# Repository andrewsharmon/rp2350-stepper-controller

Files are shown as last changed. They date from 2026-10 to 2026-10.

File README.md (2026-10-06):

# RP2350 coordinated stepper controller

> **Work in progress.** Firmware runs on a Raspberry Pi Pico 2 bench setup.
> The custom board designs are an **unreviewed feasibility first pass**:
> schematics only, no PCB layout, not checked against datasheets or built.
> Don't fabricate them as-is.

A very low-cost, compact controller for up to **10 small stepper motors** (8 mm
micro steppers, 28BYJ-48 converted to bipolar, about 0.2 A per coil or less).
It's aimed at kinetic art first, then lab and robotics use.

There are no stepper-driver ICs. The RP2350 generates sine-PWM microstepping
itself (voltage mode), using PIO state machines fed by DMA, into cheap
DRV8833-class dual H-bridges (AT8833).

## Status

| # | Milestone | State |
|---|---|---|
| 1 | Hardware spec and KiCad schematics for all three boards | first pass, **not reviewed** (open part picks in [hardware/README.md](hardware/README.md)) |
| 2 | One motor: sine PWM via PIO + DMA | done, verified on hardware |
| 3 | 10-axis PWM, ADC monitor, e-stop/button ladder, WS2812 | done on Pico 2; ladder buttons not yet bench-wired |
| 4 | Trajectory generators and profiles, jog modes, telemetry | done (text telemetry; binary framing comes with milestone 5) |
| 5 | Coordinated groups and planner, USB protocol, host tool | done |
| 6 | I²C target, cam/LED shows, flash config, standalone mode | done; I²C target written for the RP2354B board but **untested** (no free pins or I²C master on the bench) |
| 7 | PCB layout, fab, bring-up of the board stack | |

What works today (measured on a Pico 2 + DRV8833 + 8 mm stepper):

- **PWM:** 20 kHz, four-segment H-bridge PWM with slow-decay brake off-time and 1/256-step sine microstepping. Duties below the driver's 0.5 µs minimum pulse are error-diffused.
- **10 axes:** each has its own position, velocity or jog mode on a 1 kHz trajectory tick. Drive amplitude depends on speed, with lower holding current at standstill. Core 1 is about 33-35% loaded, core 0 about 0.5%.
- **Coordinated groups:** up to 4 groups, each owning a set of axes. A group follows a queue of straight lines and arcs in joint space, with every axis starting and finishing together. Lookahead keeps it moving through gentle corners and chord-split arcs, and no axis exceeds its own limits. On the Pico 2, a 300-step-radius circle ran at a constant 800 steps/s and closed exactly.
- **Shows:** keyframe tracks for axes and LED pixels on one timeline, written as JSON, compiled and uploaded to one of 4 flash slots. Axes pass exactly through every keyframe (played as PVT), LED colours fade between keys, and shows can loop. A show is refused if any segment would exceed an axis's speed or acceleration limit. On the Pico 2, a looping 10-axis wave with 9 LED tracks hit all 360 keyframes checked exactly over 2.5 loops.
- **Standalone mode:** a boot show (saved in the configuration) starts at power-up with no computer attached. Btn1 clears a latched stop once the e-stop is closed again, or starts / stops the selected show; Btn2 selects the next stored show, switching to it if one is playing.
- **Configuration in flash:** per-axis limits, motion profile, automatic amplitude curve (run low/high, hold, corner speeds) and wiring fixes (reverse direction, swap coils) survive power cycles. Two sectors are written alternately with a generation counter and CRC, so an interrupted save keeps the previous configuration.
- **Streamed PVT:** the host sends position/velocity/time points, and each axis follows a cubic through them. A 10-axis wave streamed at 20 ms per point tracked the ideal curve within 0.0005 steps. Running out of points while moving brakes safely.
- **Telemetry:** up to 1 kHz with selectable axes and fields (position, speed, mode, amplitude, PVT queue, plus motor voltage, ladder, stop state and the last applied command). Each line is numbered so a host can detect drops. Event lines report finished moves, PVT underruns and stops. At 1 kHz with every field on 10 axes, no lines were dropped and core 0 was 39% busy.
- **Electronic cams:** an axis can follow a cam table, so its position is a function of a leader's position: another axis, or one of two virtual leaders with their own speed ramps. Because it's position-based, followers retrace exactly when the leader reverses, at any speed. Cyclic tables can carry a net rise per cycle. Engaging blends in smoothly, and is refused if the follower couldn't keep up at the leader's limits. On the Pico 2, followers matched an independent evaluation of the cam within 0.0013 steps through forward and reverse runs. `save` also stores the loaded cam tables in flash; they are restored at boot.
- **Motion profiles per axis:** `trap`, `scurve` (the default: jerk-limited by a moving average, Tj = 30 ms), `smooth` (two moving averages), `cosine` and `quintic`. Every profile lands exactly on its target within the speed and acceleration limits, and moves can be redirected mid-move without jumps.
- **Safety:** an e-stop or driver fault on the analog ladder cuts all outputs in about 30 µs. A watchdog on core 0 drops outputs to coast if core 1 stalls.
- **Status LEDs:** a WS2812 chain shows overall status plus each axis's speed and direction.

How it works, from trajectory planning to PIO pin toggling: [docs/THEORY.md](docs/THEORY.md).

## Repository layout

```
tools/stepperctl/    host library + command line (binary protocol)
tools/shows/         example shows (JSON; format in tools/stepperctl/show.py)
tools/cams/          example cam tables (JSON: {"cyclic": true, "points": [[x, y], ...]})
tools/pvt_demo.py    host demo: streams a PVT wave over USB serial
firmware/            Pico SDK (C) firmware
  src/               motor PWM (PIO/DMA), microstepping, ADC monitor, ladder, LEDs
  boards/            board header for the custom RP2354B controller
  test/test_host.c   host-side tests (PWM encoder, microstep math, ladder, motion)
  tools/             sine table generator
hardware/            spec, KiCad schematics and BOMs (generated by hardware/gen)
```

## Building the firmware

Requirements:
- [Pico SDK](https://github.com/raspberrypi/pico-sdk) 2.1.1 (set `PICO_SDK_PATH`);
- an `arm-none-eabi` GCC toolchain;
- CMake and Ninja.

```bash
# Custom RP2354B controller (default board)
cmake -S firmware -B firmware/build -G Ninja
cmake --build firmware/build

# Raspberry Pi Pico 2 bench setup
cmake -S firmware -B firmware/build-pico2 -G Ninja -DPICO_BOARD=pico2
cmake --build firmware/build-pico2
```

Options: `-DNUM_MOTORS=1..10` (default 10), `-DLADDER_BYPASS=ON` (bench without
a ladder wired; never use with motors you can't stop by hand), `-DBOOT_TRACE=ON`.

Flash by copying `stepper.uf2` to the board in BOOTSEL mode, or with picotool:

```bash
picotool load -x firmware/build-pico2/stepper.uf2
```

Host tests (no hardware needed):

```bash
cd firmware/test
cc -std=c11 -O1 -Wall -Wextra -DCONFIG_HOST_TEST -I../src test_host.c ../src/hbridge_encode.c \
   ../src/microstep.c ../src/sine_lut.c ../src/ladder.c ../src/motion.c ../src/group.c \
   ../src/frame.c ../src/config.c ../src/show.c ../src/standalone.c ../src/cam.c ../src/cam_store.c \
   -lm -o test_host && ./test_host
```

## Pico 2 bench setup

| Pico 2 | Connects to |
|---|---|
| GP0-GP3 | motor 1: DRV8833 module AIN1, AIN2, BIN1, BIN2 (motors 2-5 on GP4-GP19) |
| GP20 | WS2812 chain data in (pixel 0 status, pixels 1-10 axes) |
| GP26 | ladder: 10k to 3V3, 20k to GND (idle); see [hardware/README.md](hardware/README.md) |
| GP28 | board ID (optional) |
| VBUS / GND | DRV8833 VM and GND; pull the module's sleep pin (EEP) high |

Motors 6-10 have no pins on the Pico 2, but their state machines and DMA still
run, so the full 10-axis load is exercised.

The USB serial console takes line commands (type `help`). Some examples:

```
m 1 500          move axis 1 to 500 full steps
mr * -100        move every axis back 100 steps
j 3 400          jog axis 3 at 400 steps/s (stops unless repeated within 300 ms)
lim 1 1200 4000  axis 1 limits: 1200 steps/s, 4000 steps/s^2
prof * quintic   minimum-jerk moves on every axis (axes must be at rest)
cam 1 cyclic 0,0 100,40 200,50   cam table 1 (leader x, follower y); +50 per 200-step cycle
vl 1 lim 150 150 virtual leader 1 limits; ce 3 1 v1 makes axis 3 follow cam 1 behind it
vl 1 vel 100     run the virtual leader (negative reverses; followers retrace)
g 1 1,2 800      group 1 = axes 1 and 2, path speed 800 steps/s
gl 1 400 400     group line to (400, 400); ga 1 -300 0 360: full circle around (-300, 0)
p 2 150 300 20   PVT point: axis 2 reaches 150 steps at 300 steps/s, 20 ms after the last
pgo 1,2          start axes 1 and 2 following their queued points on the same tick
t 100            100 telemetry lines/s (header line names the columns)
tf pos,vel,mode  per-axis telemetry fields; ta 1,2 picks axes, ts adds system fields
te on            event lines: E <tick> done <ax> <pos>, underrun, stop, clear
echo off         for scripts: no echo or prompt
drive 1 40 60 25 axis 1 amplitude: 40% at low speed, 60% at high speed, 25% holding
dir 2 rev        reverse axis 2 (coils 2 ba swaps its coils)
cfg / save       show the configuration / write it to flash (axes at rest)
?                status, loads and per-axis table
```

### Host tool (binary protocol)

The same USB port also speaks a framed binary protocol (COBS + CRC-16; the
message spec is [firmware/src/protocol.h](firmware/src/protocol.h)). Frames
and the text console coexist: binary frames are wrapped in 0x00 bytes, which
the console never sends. `tools/stepperctl` is a standard-library Python
client and command line:

```bash
python3 tools/stepperctl ping
python3 tools/stepperctl move 1,2 250 --wait
python3 tools/stepperctl group 1 create 1,2 --feed 800
python3 tools/stepperctl group 1 arc -200 0 360
python3 tools/stepperctl telem --hz 200 --axes 1,2 --seconds 5 > log.csv
python3 tools/stepperctl show upload tools/shows/wave.json --slot 2
python3 tools/stepperctl show run 2          # show list / show stop
python3 tools/stepperctl boot 2 && python3 tools/stepperctl save   # run show 2 at power-up
python3 tools/stepperctl cam load 1 tools/cams/rise_dwell.json
python3 tools/stepperctl cam engage 3 1 v1 && python3 tools/stepperctl vl 1 vel 100
```

```python
from stepperctl import Client          # run from tools/, or put tools/ on sys.path
with Client() as c:
    seq = c.move([1], 500)
    c.wait_settled([1], after=seq)
```

Command-line tool tests (no hardware needed):
`python3 -m unittest discover -s tools/stepperctl -p 'test_*.py' -t tools`

### I²C (Qwiic) — untested

On the RP2354B board the Qwiic port (I2C1, GPIO 46/47) is an I²C target at
address 0x42 carrying the same requests as the binary protocol, without COBS
framing: write `[type][payload…]`, then read `[n][type][reply payload…]`
(`n` = 0 means not ready yet, read again). See
[firmware/src/i2c_target.h](firmware/src/i2c_target.h). It is compiled out on
the Pico 2 bench build and has not been run on hardware yet.

`tools/pvt_demo.py` streams a travelling wave across every axis as PVT points
(standard-library Python, macOS/Linux):

```bash
tools/pvt_demo.py --amp 200 --hz 0.5 --seconds 15
```

## Notes

- **Sine table:** the SDK's float `sinf` returned wrong values near multiples
  of π/2 on the RP2350, which produced reverse pulses at each coil peak. The
  sine table is generated offline (`firmware/tools/gen_sine_lut.py`), and the
  motion code uses its own polynomials (`firmware/src/trig.h`).
- **Endless DMA:** on the RP2350, endless-mode DMA (`TRANS_COUNT` mode 0xF)
  still needs a non-zero count, or the channel completes immediately.

## License

[MIT](LICENSE), covering both firmware and hardware design files.

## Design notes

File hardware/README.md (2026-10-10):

# Hardware specification

> **Status: unreviewed feasibility first pass.** These schematics, part picks
> and pin maps were put together quickly to check that the concept fits. They
> have not been reviewed, checked against datasheets, laid out or built.
> Expect errors; don't fabricate from them as-is.

Low-cost, compact, up-to-10-axis stepper controller for small high-resistance
steppers (8 mm micro steppers, 28BYJ-48 converted to bipolar, <= 0.2 A/coil).
The MCU generates sine PWM (voltage-mode microstepping) directly into cheap
dual H-bridges; there is no stepper-driver IC.

Prefer LCSC / JLCPCB "basic" parts wherever possible. Part picks marked TBD
are open.

## Stack overview

Three boards, 30 x 30 mm core, joined by fine-pitch board-to-board (BTB)
connectors at opposite edges. No screws: the enclosure captures the stack.

| Tier | Board | Layers | Size |
|---|---|---|---|
| 1 | Controller | 4, 1.0 mm thick | 30 x 30 mm |
| 2 | Universal driver | 2 | 30 x 30 mm |
| 3 | Connector / IO (variant-specific) | 2 | sized by connectors, may overhang |

## Tier 1 - Controller

- MCU: **RP2354B** (QFN-80, 48 GPIO, 2 MB in-package flash). Run the ARM cores (FPU).
- 12 MHz crystal, core-regulator inductor and decoupling per the RP2350 hardware design guide.
  - Crystal: Abracon ABM8-272-T3 (C20625731, 10 pF load, ESR <= 50 ohm). The guide's 15 pF / 1 k values are tuned for it; other crystals need retuning and testing.
  - Inductor: Abracon AOTA-B201610S3R3-101-T has a polarity dot. Lay it out in the same orientation as the Pico 2.
- USB-C receptacle with THT shell legs. The enclosure supports the receptacle so plug forces never reach the BTBs.
- CC1 / CC2: 5.1 k pull-downs, also routed to ADC (GPIO40/41) to read the source current advertisement.
- Power path: `VBUS -> PTC (~1.5 A hold, 1812) -> low-Vf Schottky -> V5_IN -> soft-start switch -> V5 bus -> BTB`.
- 3.3 V LDO (ME6211 class, <= 6 V input) fed from V5_IN, ahead of the switch.
- Soft-start: AO3401A P-FET (C15127) with 100 nF gate-source and 100 k gate-ground (tau 10 ms). At plug-in the cap holds the FET off, then it turns on over a few ms, so the ~70 uF on the V5 bus charges at about 0.1 A. USB sees only the ~11 uF on V5_IN at attach. External 5 V (tier 3) reaches V5_IN through the FET's body diode, then its channel.
- 2x Qwiic (JST-SH 4-pin) on I2C1:
  - The board is not powered from Qwiic. The ME6211 conducts from VOUT back to VIN, so a Qwiic-fed 3V3 would back-power the V5 bus (drivers, LEDs).
  - Solder jumpers for pull-ups (2.2-4.7 k) and for supplying 3V3 to downstream Qwiic devices.
- WS2812-class addressable LED on GPIO45. Its DOUT continues down the stack as LED_DATA.
  - Powered from V5 (needs >= 3.7 V). The 3.3 V data goes through a 74AHCT1G125 on V5 to meet VIH = 0.7 VDD.
- Buttons:
  - BOOTSEL (also readable at runtime), TS-1187A, right edge below connector B. The single boards use the TS-1088-AR02016 instead (same part as Btn1/Btn2).
  - Btn1 and Btn2 on the analog ladder (see below): XUNPU TS-1088-AR02016 (C720477, 3.9 x 3.0 mm, 2 pads), stacked in the top-right corner. They started over the BTB headers for rigidity, but their pads blocked the connector fan-out, so the case should support the board under them.
- SWD test pads.

## Tier 2 - Universal driver

- 10x **AT8833CQ** (Zhongkewei, LCSC C5120769, QFN-16 4 x 4).
  - DRV8833-compatible logic: 00 coast, 01 reverse, 10 forward, 11 brake.
  - VM 2.7-15 V, UVLO <= 2.5 V, 1.0 A RMS. Inputs have 100 k pull-downs.
  - Second source: JSMSEMI DRV8833RTYR / JSM8833RTYR (same QFN-16 4 x 4). Verify its pinout against TI DRV8833RTY before relying on it.
- Passives per chip:
  - AISEN / BISEN: 0.68-0.82 ohm to ground. Above I = 0.2 V / R (Vtrip 160-240 mV) the chip chops the current in slow decay; it does not report a fault. With 0.82 ohm that is 0.2-0.29 A. Give it a separate return to the star ground.
  - VCP: 0.1 uF to VM.
  - VINT: 1 uF.
  - These are the AT8833 datasheet values. TI's DRV8833 uses 0.01 uF and 2.2 uF, so don't copy from it.
  - VM: 1-2.2 uF ceramic at the pin.
- Shared bulk: 2-4x 10 uF 0805 spread over the V5 pour.
- nSLEEP: pulled high through 20-75 k (always awake, <= 3.5 mA idle per chip).
- nFAULT (open drain): wire-OR all chips onto the LADDER line.
- VMOTOR is the V5 bus directly.
- VMOTOR_SENSE: 1:5 divider to GPIO42.

AT8833CQ QFN-16 pinout: 1 AISEN, 2 AOUT2, 3 BOUT2, 4 BISEN, 5 BOUT1, 6 nFAULT,
7 BIN1, 8 BIN2, 9 VCP, 10 VM, 11 GND, 12 VINT, 13 AIN2, 14 AIN1, 15 nSLEEP,
16 AOUT1, plus the exposed pad to GND.

## Tier 3 - Connector / IO

- Motor connectors per variant. Each uses the motor's stock plug:
  - `io_xh`, 28BYJ-48: one JST-XH 5-pin (B5B-XH-A, C157991) per motor, ten total.
    - Pins: 1 blue, 2 pink, 3 yellow, 4 orange. Pin 5 (red centre tap) is not connected after the bipolar mod.
    - Coils: A = pins 1/3, B = pins 2/4.
  - `io_sh`, dual 8 mm micro steppers: one JST-SH 8-pin (BM08B-SRSS-TB, C160394) per motor pair, five total.
    - Pins 1-4 = first motor (A1 A2 B1 B2), pins 5-8 = second motor.
  - Firmware remaps coil order and polarity per axis, so lead-colour variations can be fixed in software.
- Optional external 5 V input -> Schottky -> V5 bus. This powers everything without USB.
- LED strip output (V5 / DATA / GND):
  - Data: 74AHCT1G125 buffer (powered from V5), then a 33-100 ohm series resistor.
  - Strip power, chosen by footprint: shared V5 through a polyfuse, or a separate LED power input.
- E-stop jack and panel buttons, in parallel with the ladder.
- Board ID: one resistor to GND, read through the controller pull-up on GPIO43. See the board-ID table below.

## Interconnect (BTB)

- **Part:** Hirose DF40, 0.4 mm pitch, 40 pins, **2.0 mm stack height**:
  - **Header** DF40C-40DP-0.4V(51) (C424643). Goes on the **underside of the upper board**. The header is the same for every DF40 stack height.
  - **Socket** DF40C(2.0)-40DS-0.4V(51) (C597934). Goes on the **top of the lower board**. The socket sets the stack height.
  - Rated 0.3 A per contact. The four corner contacts (pins 1, 2, 39, 40) are metal fittings per Hirose (catalogue note 3): they are soldered for strength but left unconnected, leaving 36 usable pins.
  - The 2.0 mm stack leaves room between boards for low parts (0402 passives, QFNs, SOT-23) on the facing sides. Keep anything taller than ~1 mm off them, and don't put a part opposite another one on the facing board if the two heights add up to more than ~1.7 mm.
- **Footprints** are in `lib/stack.pretty`, generated by `gen/footprints.py` from the DF40 catalogue's recommended layouts:
  - Socket: 0.20 x 0.70 pads (rows 2.38-3.78 mm across), plus the 1.5 mm layout-prohibited strip between the rows as a copper keepout.
  - Header: 0.23 x 0.66 pads (rows 2.05-3.37 mm across), plus 0.35 mm metal-fitting tabs 0.30-0.65 mm beyond each row end.
  - Pin 1 at -X. The socket's odd row is at -Y; the header's is drawn at +Y, so after the flip onto the underside header pin n sits over socket pin n. Still check it in the 3D viewer before ordering.
- **Not polarized** (Hirose note 5). Two connectors per interface at offset positions key the stack so the boards only mate one way: A is 2 mm below the board centre line, B on it.
- BTB pins carry roughly 0.3-0.5 A each.
- The authoritative pin lists are `btb_a()` and `btb_b()` in `gen/build.py`.

| Connector | Controller <-> driver | Driver <-> tier 3 |
|---|---|---|
| A | motors 1-7 inputs (28), 4x V5, 3x GND, 3V3, 4 corner NC | motors 1-7 outputs (28), 4x V5, 4x GND, 4 corner NC |
| B | motors 8-10 inputs (12), LED_DATA, LADDER, BOARD_ID, VMOT_SENSE, 9x V5, 11x GND, 4 corner NC | motors 8-10 outputs (12), LED_DATA, LADDER, BOARD_ID, 9x V5, 12x GND, 4 corner NC |

Pin order follows the MCU's pin order, so the controller's traces fan in without crossing. Connectors are placed pin 1 at the top: A down the left edge (power, then M1 from the MCU's top-left corner, M2-M5 down its left side, M6-M7 round its bottom-left), B down the right edge (utilities, then M10, M9, M8). M6/M7 are on A so they don't cross the crystal and SWD pins on the MCU's bottom side. The driver board shares V5 between both connectors, so the uneven V5 split doesn't matter. The driver's sockets copy the controller headers' positions and rotation.

**Board ID:** the 10 k 1% pull-up to 3V3 is on the controller. Each tier-3 variant fits one resistor to GND, 5% is fine. With no tier 3 attached, the line reads 3.3 V.

The values are common 0402 parts. Ranges are worst case for a 5% ID resistor and the 1% pull-up; adjacent levels stay at least 249 mV apart, and the thresholds sit midway between ranges.

| ID resistor | Nominal | Range (mV) | Threshold above (mV) | Board |
|---|---|---|---|---|
| 0 ohm | 0 mV | 0 | 150 | |
| 1 k | 300 mV | 284-316 | 440 | |
| 2.2 k | 595 mV | 566-624 | 820 | |
| 4.7 k | 1055 mV | 1012-1098 | 1350 | io_sh (dual 8 mm micro steppers) |
| 10 k | 1650 mV | 1599-1699 | 1960 | io_xh (28BYJ-48) |
| 22 k | 2269 mV | 2225-2310 | 2500 | |
| 47 k | 2721 mV | 2691-2749 | 3020 | |
| not fitted | 3300 mV | 3300 | - | no tier 3 attached |

## GPIO map (RP2354B)

| GPIO | Function |
|---|---|
| 0-39 | Motor n (1-10) on GPIO 4(n-1)..4(n-1)+3 = AIN1 AIN2 BIN1 BIN2 |
| 40 | USB-C CC1 (ADC0) |
| 41 | USB-C CC2 (ADC1) |
| 42 | VMOTOR_SENSE, 1:5 (ADC2). Can't tell external power from USB (both feed V5 through Schottkys) |
| 43 | Tier-3 board ID (ADC3) |
| 44 | Ladder (ADC4) |
| 45 | WS2812 data |
| 46 | Qwiic SDA (I2C1) |
| 47 | Qwiic SCL (I2C1) |

PIO allocation:

| PIO block | State machines | Use |
|---|---|---|
| PIO0 | SM0-3 | Motors 1-4 |
| PIO1 | SM0-3 | Motors 5-8 |
| PIO2 (GPIOBASE = 16) | SM0-1 | Motors 9-10 |
| PIO2 | SM2 | WS2812 |
| PIO2 | SM3 | Spare |

Use external pull-ups on all inputs on A2 silicon (RP2350-E9 erratum; fixed from A3).

## Ladder on GPIO44

```
3V3 --[10k]--+---------> GPIO44 (ADC4), 100 nF to GND
             |-- E-stop (NC) --[20k]-- GND   (solder jumper bypass when no e-stop)
             |-- Btn1 ---------[10k]-- GND
             |-- Btn2 ---------[3.3k]- GND
             '-- nFAULT (open drain, all drivers)
```

| Condition | Voltage | Meaning |
|---|---|---|
| E-stop open or cable cut | 3.3 V | STOP |
| Idle | ~2.2 V | normal |
| Btn1 | ~1.3 V | user 1 |
| Btn2 | ~0.7 V | user 2 |
| nFAULT | ~0 V | driver fault, STOP |

Use 1% resistors. Thresholds sit midway between the levels; debounce over 2-3 samples.

A held button hides an open e-stop (e-stop open + Btn1 = 1.65 V, + Btn2 = 0.82 V). Firmware latches a stop on 1.49-1.76 V held 5 ms, or on any button held over 3 s; see `firmware/src/ladder.h`.

## Electrical notes

- PWM frequency is about 20 kHz. The AT8833 input deglitch (about 450 ns) sets a minimum pulse of about 0.5 us, roughly 1% duty. Firmware dithers duties below that.
- Wait about 100 ms after power-up before energizing motors (V5 soft-start settling).
- USB budget comes from CC; brownout guard from VMOTOR_SENSE.
- RP2350-E9 (a GPIO with its input buffer on can sit near 2.2 V, which the AT8833's >= 2 V VIH reads as high) needs no hardware fix on the motor inputs. It is fixed in silicon from A3 (A4 is the production stepping; order A4). On A2 it can't occur after a power-on or RUN reset (input enable starts clear), and the firmware turns the motor pins' input buffers off (they are never read), so they stay off across a watchdog reset whether or not it resets the pads. The AT8833's 100 k pull-downs are enough.
- Tier 3: the NO_ESTOP jumper ships bridged. It must be cut when an e-stop is fitted, or the e-stop does nothing. Mark this on the silkscreen.

## Single board (`single_sh`)

Controller, driver and the `io_sh` connectors on one PCB, from the `single_sh/` schematic (`single()` in `gen/build.py`). Fully routed: 0 unconnected, no DRC errors, schematic parity clean.

- Schematic: a wired, hierarchical drawing (`gen/single_sh_sch.py`), unlike the label-only stack schematics.
  - Sheets: overview, power and USB, MCU, motor drivers, connectors and UI. Each block is framed, with design notes on its sheet.
  - Inter-sheet signals (motor lines, LADDER, BOARD_ID, I2C, CC, USB) are global labels. Power rails are power symbols, so their PCB nets are `GND`, `+3V3`, `V5` and so on; nets local to a sheet are named `/<sheet>/<label>`, e.g. `/Power/V5_IN`.
  - The AT8833 uses a project symbol (`lib/stack.kicad_sym`, written by `build.py`) with the DRV8833RTY pin numbers, laid out for the drawing; VINT is typed as an output, so it needs no PWR_FLAG.

- **122 x 20 mm**, 4 layers, 1.6 mm thick. All parts on top; only the THT legs of the USB-C and the JST-PH/XH connectors come through.
- Layers: F.Cu parts and signals, In1 solid GND, In2 V5, B.Cu signals. In2 has a 3V3 island under the MCU, joined to the LDO by a thin finger along the -y edge.
- Along the board: USB-C (mouth on the short edge) and power path | drivers M4 M3 M2 M1 | MCU | drivers M10 M9 M8 M7 M6 M5 | LED strip connector.
  - Motor connectors run along one long edge in the order J12 J11 | J15 J14 J13, so each motor bus leaves the MCU in pin order and never crosses itself.
  - Qwiic x2, BOOTSEL, e-stop, panel buttons, 5 V in, status LED and LED power run along the other long edge, above the drivers.
- Driver cell: AT8833 rotated so its outputs face the connector. VINT/VM/VCP caps sit above it; the 0603 sense resistors sit below, ISEN pads inboard, each GND pad with its own via (R16 and R20 instead tie to the neighbouring cell's GND pad).
  - BOUT2 runs down between the two ISEN pads and BOUT1 under R_B's body. The resistors went 0805 -> 0603 in place on the routed board: pad 1 (ISEN) kept, GND pad 0.275 mm inboard (R5 and R11 keep the GND pad instead, clear of a neighbouring via and track).
  - The connector's pin order (B2 B1 A2 A1, left to right) runs against the driver's (A1 A2 B2 B1), so A1/A2 hop over B1/B2 on short In2 jumpers (4 vias per motor).
  - Swapping this board's connector pin assignment (pins 1-2 = coil B, pins 3-4 = coil A reversed) would remove the jumpers, if firmware maps coil order and polarity per board. Not done, because the cable pinout would then differ from `io_sh`.
- V5 enters the In2 plane through via clusters at the soft-start FET, the external 5 V diode and the LED-strip fuse.
- Layout source: `single_sh()` in `gen/pcbgen.py` (placement and zones).
  - The driver cells and the core regulator were pre-routed by script. The rest was routed with Freerouting 2.5.0 plus a small grid router.
  - Those routing scripts are not in the repo; the board is hand-edited from here.
- Silkscreen: reference designators are hidden (too dense).
  - Motor numbers sit above each connector; function labels are on top where they fit, otherwise on the underside.
  - The underside also carries the NO_ESTOP cut warning.
  - The 4 remaining silkscreen warnings are outlines touching each other or the board edge.

### Fabrication (JLCPCB)

`gen/jlcfab.py` writes the order files to `single_sh/jlcpcb/`: Gerbers + Excellon drill (zipped), the BOM and the placement (CPL) file. Run it with KiCad's Python; `--check` also verifies the placements.

```bash
/Applications/KiCad/KiCad.app/Contents/Frameworks/Python.framework/Versions/Current/bin/python3 gen/jlcfab.py single_sh --check
```

- JLCPCB places each part with its own library footprint, so `CPL_FIX` corrects rotation and origin per LCSC part (SOT-23, SOT-23-5, WS2812, the JST connectors and USB-C need it).
  - `--check` fetches those footprints from the JLCEDA library and compares their pads with the KiCad pads.
  - All 142 placements land within 0.003 mm of centre with every pin on its own pad.
- Pin numbering traps:
  - SS54 (C22452): JLCPCB numbers 1 = anode, 2 = cathode, the reverse of KiCad's diodes. `PAD_MAP` handles it; the diodes need no extra rotation.
  - AOTA inductor (L1): the dot goes at the +1V1 end, as on the Pico 2 (RP2350 datasheet, regulator layout figure). JLCPCB's silkscreen and Abracon's top view put the dot at their pad 2, so pad 2 lands on +1V1. JLCPCB's placement preview shows the dot there; the order remark repeats it.
- The BOM has one line per LCSC part. JLCPCB unticks a part that appears on several lines.
- First order (2026-10-07, 10 boards, $314 before shipping):
  - PCB: 4 layers, 1.6 mm, ENIG (0.4 mm pitch QFN-80), min via 0.15/0.3 mm, plugged vias.
  - Assembly: Standard PCBA, top side, confirm parts placement with no auto-confirm.
- Cost drivers:
  - The 0.15 mm via option ($37) forces a 4-wire Kelvin test ($18) and TG155.
  - The WS2812B-2020 (D2) is Standard-PCBA only, as are its alternatives. Standard adds $25 setup, feeder fees and 5 mm edge rails (a 122 x 70 mm panel, nearly double the shipping weight). Economic with D2 left off was $265.
  - THT parts (JST PH/XH, the USB-C shell legs) are hand soldered, about $6.
- Vias sit in the QFN exposed pads and in U11 pin 59 (+3V3). JLCPCB doesn't offer tented for this board; plugged (solder mask) is the free option. Epoxy filled & capped costs about $20 more if those joints give trouble.

## Schematics and BOM

Schematics are generated. Edit `gen/build.py`, not the `.kicad_sch` files. For `single_sh`, part placement and wiring live in `gen/single_sh_sch.py`.

```bash
python3 gen/footprints.py   # project footprints -> lib/stack.pretty
python3 gen/build.py        # schematics
```

The controller and `single_sh` PCBs were started by `gen/pcbgen.py <board>`, run once with KiCad's Python
(it needs `pcbnew`); it refuses to overwrite an existing board. It set up the
outline, stackup, JLCPCB rules and net classes, and a first placement of every
part. From there the layout is edited by hand in KiCad.

```bash
/Applications/KiCad/KiCad.app/Contents/Frameworks/Python.framework/Versions/Current/bin/python3 gen/pcbgen.py controller
```

Outputs:

- `controller/`, `driver/`, `io_xh/` (28BYJ-48), `io_sh/` (micro steppers): one KiCad schematic each.
- `single_xh/`, `single_sh/`: the whole circuit (controller + driver + that IO variant) on one board, with the BTB connectors removed and their nets joined directly. `single_sh` has a routed PCB (see above); `single_xh` is schematic only.
- Each part's pins are connected by net labels, except in `single_sh`, which is drawn with wires (`gen/single_sh_sch.py`, using `gen/schdraw.py`).
  - Before writing, `schdraw` traces the drawing the way KiCad does (wires, junctions, labels, power symbols) and fails unless every pin is on exactly the net `build.py` gave it.
  - Moving or adding a part in `build.py` means placing it in `single_sh_sch.py` too; an unplaced part, unwired pin or short stops the build.
  - Refs and symbol UUIDs are what the routed PCB links to. Changing a net's name or sheet changes its PCB net name: run Update PCB from Schematic in KiCad afterwards.
- `*_bom.csv` in each folder, exported with `kicad-cli sch export bom` (grouped by value, footprint, LCSC, MPN and note).

Part data:

- Every BOM line has an LCSC number, checked against the JLCPCB parts library on 2026-10-07 (part, package, rating, stock). Passives take theirs from `PASSIVES` in `gen/build.py`.
- JLCPCB basic parts where one exists. Extended lines: RP2354B, AT8833CQ, 3.3 uH inductor, crystal, ESD diode, LDO, AHCT buffer, status LED, polyfuse, USB-C, the JST connectors, and three passives:
  - 2.2 uF VM caps: the only basic 0402 2.2 uF is rated 6.3 V, so a 16 V part is used on the 5 V motor rail.
  - 0.82 ohm sense resistors (0603, 250 mW): no basic part exists.
  - 27 ohm USB series resistors and the 39 k VMOT_SENSE divider resistor: no basic 0402 part exists.
- Solder jumpers and test pads are excluded from the BOM and from the placement file (they are copper only).

Open items:

- Soft-start: measure the inrush on the first boards and adjust the 100 nF / 100 k if needed.
- Stock to watch (JLCPCB, 2026-10-07):
  - AOTA-B201610S3R3-101-T inductor: 677 in stock (662 when the first order was prepared).
  - RP2354B: about 1.7k in stock.
  - Polyfuse: 1.97k in stock. Ruilon C702823 isn't in JLCPCB's library, so PTTC SMD1812P150TF/8 (C209721) is used.
  - Status LED: the Worldsemi WS2812B-2020 (C965555) had 1 in stock, so the XINGLIGHT XL-2020RGBC-WS2812B (C5349955) is used. It has the same pinout and footprint.
- Sense resistors: 0603, 250 mW (Viking SR731JTTDR820F, C186570; 2.2k in stock 2026-10-10). Holding a coil at the AT8833 current-limit trip (up to 0.29 A at VTRIP 240 mV) dissipates 69 mW, 28 % of rating. The worst case is VTRIP^2 / R, so a lower R for more current needs R >= 0.29 ohm to keep 20 % margin. Most 0603 0.82 ohm parts are 100 mW (69 %); keep a 250 mW part if this one is substituted.
- LED PWR (J6) is a JST-PH rated 2 A per pin, which caps a separately powered strip at 2 A unless the connector changes.
- PCB layout: controller fully routed (0 unconnected; silkscreen labels still to tidy); `single_sh` fully routed (unreviewed); driver and tier-3 boards not started. Routing used Freerouting 2.5.0 plus a small grid router for the last nets; neither is part of the repo.

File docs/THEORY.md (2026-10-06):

# Theory of Operation

How the firmware turns a command such as "move axis 3 to 500 steps" into
current in a stepper coil: through trajectory planning, a 1 kHz motion tick,
20 kHz sine microstepping, PWM encoding, and PIO pin toggling fed by DMA.
The end of the document covers every motion mode and the extra features
(groups, PVT, cams, shows, safety, configuration).

Source references are in `firmware/src/`. The diagrams use Mermaid, which
GitHub renders.

---

## 1. Big picture

There are no stepper driver ICs. The RP2350 works out the coil voltages
itself (voltage-mode sine microstepping) and drives cheap AT8833/DRV8833 dual
H-bridges directly, four GPIOs per motor, for up to 10 motors.

The two cores divide the work strictly:

| Core | Job | Timing |
|---|---|---|
| **Core 0** | USB console, binary protocol, I²C target, show player, LEDs, telemetry, flash, buttons, core 1 watchdog | best effort, ~0.5 % idle load |
| **Core 1** | every axis's trajectory, interpolation, amplitude, microstepping, PWM encoding, DMA rings, e-stop ladder | hard real time, ~33–35 % load |

```mermaid
flowchart LR
    subgraph Host
        USB[USB serial<br/>text console + COBS frames]
        I2C[Qwiic I²C target]
        BTN[Ladder buttons]
    end

    subgraph Core0[Core 0: non-real-time]
        CON[console.c / protocol.c]
        I2CT[i2c_target.c]
        PLY[player.c<br/>show → PVT feed]
        SA[standalone.c]
        WD[core 1 watchdog]
        LED[led.c WS2812]
        CFG[config / show / cam store<br/>flash]
    end

    Q[(Command queue<br/>64 × control_cmd_t)]
    SNAP[(Snapshot<br/>seqlock)]

    subgraph Core1[Core 1: control_core1_main]
        APPLY[apply commands]
        TICK[1 kHz motion tick<br/>vleaders → groups → axes → cams]
        INT[per-period interpolation]
        MS[microstep: sine LUT +<br/>error diffusion]
        ENC[hbridge_encode<br/>4 segments/period]
        LAD[ladder poll<br/>every 10 µs]
    end

    subgraph HW[Hardware]
        RING[DMA ring per motor<br/>64 periods = 3.2 ms]
        PIO[PIO SM per motor]
        HB[AT8833 H-bridge]
        M((Stepper))
        ADC[ADC round robin DMA]
    end

    USB --> CON
    I2C --> I2CT --> CON
    BTN --> ADC
    CON --> Q
    PLY --> Q
    SA --> PLY
    Q --> APPLY --> TICK --> INT --> MS --> ENC --> RING --> PIO --> HB --> M
    TICK --> SNAP --> CON
    SNAP --> PLY
    SNAP --> LED
    ADC --> LAD
    LAD -- stop --> PIO
    WD -. heartbeat .- Core1
```

Core 0 never touches motion state directly. It **posts** commands into a
lock-free 64-entry queue (`control_post`, each stamped with a sequence
number) and **reads** state from a snapshot that core 1 publishes every tick
under a sequence lock (`control_snapshot`). Commands report back through
`last_seq` (the last command applied) and `rejected` (commands core 1
refused, such as a move on a grouped axis).

---

## 2. Units and number formats

Everything hinges on one choice of fixed-point position:

```
1 full step          = 2^30 units      (MOTION_UNITS_PER_STEP)
1 electrical cycle   = 4 full steps = 2^32 units
```

Position is an `int64_t`. Its **low 32 bits are exactly the electrical phase**
of the motor, so microstepping needs no conversion: `phase = (uint32_t)pos`.
Wrapping is free, the resolution is about 10⁻⁹ step, and the range is about
8.6 × 10⁹ full steps, so long moves never lose a unit.

Speeds are `float` full steps/s and accelerations full steps/s².

---

## 3. The rate pyramid

```mermaid
flowchart TB
    A["Commands (any rate)<br/>host, show player, buttons"] --> B
    B["Trajectory tick: 1 kHz (MOTION_TICK_HZ)<br/>generators, filters, groups, cams, amplitude target"] --> C
    C["PWM period: 20 kHz (HBRIDGE_PWM_HZ)<br/>20 periods per tick: phase interpolation, amplitude slew,<br/>sine lookup, error diffusion, encoding"] --> D
    D["PIO clock: 75 MHz (150 MHz / 2)<br/>3750 clocks per period, 4 segments, pin patterns"]
```

Core 1 doesn't run on a timer interrupt. It runs a tight loop that keeps
every motor's DMA ring full. Each pass:

1. Find `n`, the smallest number of free PWM periods across all rings.
2. For each of those `n` periods:
   * if this is period 0 of a tick (`sub == 0`), run the 1 kHz motion tick;
   * for each motor, compute one PWM period and append it to its ring.

The DMA drains the rings at exactly 20 kHz, so the PWM clock paces the
motion tick. The ring holds 3.2 ms of output, so core 1 can be late by up
to about 3 ms without any glitch at the motor.

---

## 4. Trajectory planning (one axis): `motion.c`

Each axis is a `motion_axis_t`, split into a **raw generator** and an
**output filter**:

```mermaid
flowchart LR
    CMD[command<br/>move / vel / jog / pvt] --> GEN
    subgraph motion_tick
        GEN["generate()<br/>gen_pos, gen_vel"] -->|"Δ = gen_pos − gen_last<br/>(units per tick)"| F1
        F1["moving average 1<br/>(scurve, smooth)"] --> F2["moving average 2<br/>(smooth)"]
        F2 --> OUT["pos += Δ<br/>vel = Δ·1000/2^30"]
    end
    GRP[group_tick] -. writes gen_pos .-> GEN
    CAMT[cam_tick] -. writes gen_pos .-> GEN
```

### 4.1 Generators

**Trapezoid, the exact discrete stopping law.** In position mode, every tick
the generator picks the fastest next speed `u` that can still stop exactly
on the target. It solves

```
(v + u)/2 · dt  +  u² / (2a)  ≤  distance remaining
```

for `u`, clamps the result to `vmax`, and moves toward it by at most
`a·dt`. Because this is the discrete law (not the continuous `v = √(2ad)`),
the ramp never overshoots. When a tick would reach the target at a speed it
could stop from in one tick, the generator snaps exactly onto the target.
Retargeting mid-move is free: the next tick simply uses the new distance.

**Velocity and jog** move `gen_vel` toward `cmd_vel` at `amax`. Jog also
counts down a watchdog: if the host doesn't refresh it within the timeout,
`cmd_vel` becomes 0 and the axis ramps to a stop.

**Cosine and quintic (fixed time).** At the start of the move,
`start_segment` picks the shortest duration `T` that respects the limits.
From rest:

| shape | peak v | peak a |
|---|---|---|
| cosine | π/2 · d/T | π²/2 · d/T² |
| quintic (minimum jerk) | 15/8 · d/T | 10/√3 · d/T² |

A quintic retargeted mid-move is re-solved with the current `v₀` and `a₀` as
boundary conditions. `T` is stretched by 15 % per iteration until a sampled
check passes. Each tick advances by Simpson's rule on the velocity (not by
evaluating `x(t)` in float), and every few ticks the generator re-syncs to
the exact double-precision curve, spreading the correction over the next
interval.

### 4.2 S-curve filters

`scurve` and `smooth` don't use a separate jerk-limited planner. They run the
trapezoid's **per-tick position deltas** through one or two moving averages
of length `Tj` (`jerk_ms`, up to 100 ms):

```mermaid
xychart-beta
    title "Velocity: trapezoid vs moving-averaged (conceptual)"
    x-axis "time" [0,1,2,3,4,5,6,7,8,9,10,11,12]
    y-axis "v" 0 --> 10
    line [0,4,8,10,10,10,10,10,10,8,4,0,0]
    line [0,2,5,8,9.5,10,10,10,10,9.5,7,3,0.5]
```

* One stage turns each step in acceleration into a ramp: jerk = `amax / Tj`.
* Two stages make the jerk itself continuous.
* Averaging never raises peak speed or acceleration.
* The integer remainder of each division is **carried**, so the filtered
  total equals the input total exactly: the output lands on the target to
  the unit.

The cost is a lag of `Tj` per stage. An axis counts as `settled` only once
the generator is idle **and** the filters have flushed. Profile changes are
accepted only while settled.

PVT and cam followers set `unfiltered` and bypass the filters, because their
input is already smooth and a lag would break their timing.

---

## 5. Core 1 motion tick ordering

Order matters, because some axes read others' positions in the same tick:

```mermaid
sequenceDiagram
    participant Q as Command queue
    participant VL as Virtual leaders (2)
    participant G as Groups (4)
    participant AX as Normal axes
    participant CAM as cam_tick
    participant FW as Follower axes
    participant AMP as Amplitude / snapshot

    Q->>Q: apply() every pending command
    VL->>VL: motion_tick (trapezoid)
    G->>AX: group_tick writes members' gen_pos
    AX->>AX: motion_tick (non-followers)
    CAM->>FW: gen_pos = f(leader.pos) + offset (+ blend)
    FW->>FW: motion_tick (followers)
    AMP->>AMP: Δpos per axis → per-period step, want_amp, publish()
```

---

## 6. From a 1 ms tick to 20 PWM periods: interpolation

After the tick, each axis has moved `Δ = pos_now − pos_before` units. That
movement is spread evenly over the next 20 PWM periods:

```
q     = Δ / 20            (64-bit: Δ can exceed 2^31 above ~2000 steps/s)
rem   = Δ − 20q
step  = q, plus ±1 for the first |rem| periods
```

so after 20 periods the electrical phase has advanced by **exactly** Δ. The
microstep phase therefore never drifts from the trajectory position, and on
an e-stop clear it is resynced with `phase = (uint32_t)pos`.

The result is piecewise-linear phase at 20 kHz, which follows the 1 kHz
trajectory with sub-microstep resolution.

---

## 7. Drive amplitude (voltage-mode current control)

With no current sensing, the coil current is set by the PWM **amplitude**, a
0..1 fraction of the full duty span. Each tick computes a target:

```mermaid
flowchart TD
    E{energized?} -- no --> Z[0]
    E -- yes --> MAN{manual amp ≥ 0?}
    MAN -- yes --> MV[manual value]
    MAN -- no --> H{settled for<br/>hold_delay_ms?}
    H -- yes --> HOLD[amp_hold]
    H -- no --> CURVE["auto_amplitude(|v|)"]
```

```
amp
 ^          amp_high ________
 |                  /
 |                 /   (linear: makes up for back-EMF)
 | amp_low _______/
 +----------------+------+-------> |speed|
              low_speed  high_speed
```

Standstill heats the coils most, so after the hold delay the axis drops to
`amp_hold`. At each PWM period the actual amplitude slews toward the target
at 2.0 per second (`AMP_SLEW_PER_SEC`), so run/hold changes don't jerk the
rotor.

---

## 8. Sine microstepping: `microstep.c`

```mermaid
flowchart LR
    P["phase (u32)"] -->|">> 22"| IDX[idx 0..1023]
    IDX --> SIN["LUT[idx] → sin (Q15)"]
    IDX -->|"+256"| COS["LUT[idx+256] → cos"]
    SIN --> SB["× amp × max_duty / 32767"]
    COS --> SA["× amp × max_duty / 32767"]
    SA --> DA[error diffusion A]
    SB --> DB[error diffusion B]
    DA --> SW[swap coils / reverse flags]
    DB --> SW
    SW --> OUTD[duty_a, duty_b<br/>signed counts]
```

* **Lookup table:** 1024 entries per electrical cycle, which is 256 entries
  per full step (1/256 microstepping). Coil A gets cosine and coil B gets
  sine, a quarter cycle apart. The table is generated offline
  (`tools/gen_sine_lut.py`) because the SDK's `sinf` misbehaved near
  multiples of π/2 on the RP2350.
* **Error diffusion:** the exact duty is fractional, and the driver swallows
  pulses shorter than ~450 ns. Each coil keeps a `carry`: rounding residue,
  and any duty below `min_duty` (500 ns ≈ 38 counts), are added to the next
  period instead. The **average** duty therefore matches the request even
  near the zero crossings, where a naive driver would produce a dead zone.
* **Wiring fixes:** `SWAP_COILS` exchanges A and B, and `REVERSE` negates B
  (which reverses rotation).

---

## 9. PWM encoding: `hbridge_encode.c`

At 150 MHz / 2 the PIO runs at 75 MHz, so a 20 kHz period is **3750 SM
clocks**. Each period is four segments, and each segment is a 16-bit
half-word:

```
bits [3:0]   pin pattern: AIN1 AIN2 BIN1 BIN2
bits [15:4]  length L; the segment lasts L + 3 clocks
```

The usable span is `3750 − 4×3 = 3738` counts per coil. For signed duties
`a` and `b`:

```
|<-- min(|a|,|b|) -->|<-- |hi|-|lo| -->|<----- rest/2 ----->|<----- rest/2 ----->|
 both coils driven     longer coil only     both braked           both braked
 (seg 1)               (seg 2)              (seg 3)               (seg 4)
```

| Pattern | Meaning |
|---|---|
| `xIN1=1, xIN2=0` | forward drive |
| `xIN1=0, xIN2=1` | reverse drive |
| `xIN1=1, xIN2=1` | **brake** (slow decay: both low-side FETs on, coil current recirculates) |

The off-time is brake (slow decay) rather than coast, which gives smoother
current at low duty. The brake time is split in two segments only so each
length fits in 12 bits.

The two half-words of segments 1–2 form word 0, and segments 3–4 form
word 1: **two 32-bit words per period per motor**.

---

## 10. DMA rings and the PIO program: IO toggling

```mermaid
flowchart LR
    C1[core 1<br/>hbridge_write_period] -->|"w0,w1 at wr"| R
    subgraph R[Ring: 128 words, aligned, wraps on 512 B]
        direction LR
        r0[...] --- r1[w0] --- r2[w1] --- r3[...]
    end
    R -->|"DMA, endless, DREQ = TX FIFO"| F[TX FIFO<br/>joined, 8 deep]
    F -->|autopull 32| SM[PIO SM]
    SM -->|out pins,4| G[GPIO 4n..4n+3]
```

The PIO program is three instructions:

```
.wrap_target
    out pins, 4      ; set AIN1 AIN2 BIN1 BIN2 for this segment
    out x, 12        ; segment length
seg_loop:
    jmp x-- seg_loop ; wait L+1 clocks (plus 2 for the outs = L+3)
.wrap
```

* **One state machine per motor:** motors 0–3 on PIO0, 4–7 on PIO1, 8–9 on
  PIO2. All SMs in a block start with `pio_enable_sm_mask_in_sync`, so the
  periods stay phase-aligned.
* **The DMA** runs in endless mode with ring wrap (`channel_config_set_ring`,
  9 address bits = 512 B), paced by the SM's TX FIFO DREQ. It replays the
  ring forever, and core 1 only has to stay ahead of the read pointer
  (`hbridge_free_periods`, with one period of slack).
* **Fail safe:** if the FIFO ever runs dry, the SM stalls holding its last
  pattern. The encoder always ends a period with brake, so a stall leaves
  both coils shorted, with no drive.
* `hbridge_safe_off` aborts the DMA, stops the SM, and hands the pins to SIO
  driven low (coast). It is used by the e-stop and the core 1 watchdog,
  because a stalled producer would otherwise leave the ring replaying stale
  periods.

### End-to-end timing of one period

```mermaid
gantt
    dateFormat X
    axisFormat %s
    title One 50 µs PWM period (|a| = 2000, |b| = 800 of 3738)
    section Coil A
    drive        :a1, 0, 2003
    brake        :a2, after a1, 3750
    section Coil B
    drive        :b1, 0, 803
    brake        :b2, after b1, 3750
```

---

## 11. Motion modes

```mermaid
stateDiagram-v2
    [*] --> IDLE
    IDLE --> POSITION: MOVE / MOVE_REL
    IDLE --> VELOCITY: VELOCITY
    IDLE --> JOG: JOG
    IDLE --> PVT: PVT_START (points queued, at rest)
    IDLE --> GROUP: GROUP_CREATE (settled)
    IDLE --> CAM: CAM_ENGAGE (settled)
    POSITION --> POSITION: retarget
    POSITION --> VELOCITY: VELOCITY
    VELOCITY --> POSITION: MOVE
    POSITION --> IDLE: arrived
    VELOCITY --> IDLE: STOP → v=0
    JOG --> IDLE: timeout / STOP → v=0
    PVT --> IDLE: last point, v=0
    PVT --> VELOCITY: underrun while moving (brake at amax)
    GROUP --> IDLE: GROUP_RELEASE (at rest)
    CAM --> VELOCITY: STOP (disengage, ramp down)
    POSITION --> IDLE: e-stop (halt)
```

| Mode | What drives `gen_pos` | Notes |
|---|---|---|
| `IDLE` | nothing | holds; drops to hold amplitude after `hold_delay_ms` |
| `POSITION` | trapezoid stop law, or a cosine/quintic segment | retargetable mid-move, lands exactly |
| `VELOCITY` | ramp to `cmd_vel` at `amax` | `STOP` ramps to 0 |
| `JOG` | as velocity, plus a timeout | stops unless refreshed (default 300 ms from the console) |
| `PVT` | cubic Hermite between streamed points | queue of 32 per axis; underrun → safe brake |
| `GROUP` | `group_tick` | individual motion commands refused; `STOP` stops the group |
| `CAM` | `cam_tick`: `f(leader)` | motion commands refused; `STOP` disengages |

### Profiles (per axis)

| Profile | Generator | Filter | Use |
|---|---|---|---|
| `trap` | stop law | none | fastest, step changes in acceleration |
| `scurve` (default, Tj 30 ms) | stop law | 1 moving average | limited jerk |
| `smooth` | stop law | 2 moving averages | continuous jerk |
| `cosine` | fixed-time cosine | none | smooth, symmetric moves from rest |
| `quintic` | minimum-jerk quintic | none | smoothest point to point; retargets with v₀ and a₀ |

---

## 12. Coordinated groups: `group.c`

A group (up to 4) owns a set of axes and moves them along a queue of up to
32 straight **joint-space segments**, so every member starts and finishes
each segment together.

```mermaid
flowchart LR
    L[GROUP_LINE / GROUP_ARC] --> SEG["segment: unit vector u,<br/>length, path vmax/amax"]
    SEG --> JN["junction speed:<br/>per-axis Δv ≤ amax·corner_s"]
    JN --> PLAN["backward pass:<br/>v_entry = min(v_junction, √(v_next² + 2aL))"]
    PLAN --> EXEC["group_tick:<br/>stop law along the path<br/>to v_exit of the next segment"]
    EXEC --> AX["member gen_pos = start + u·s"]
    AX --> FILT[each axis's own s-curve filter]
```

* **Path limits:** the segment's path `vmax`/`amax` is the largest value for
  which no member exceeds its own limits (scaled by its share of `u`).
* **Corners:** the junction speed is capped so that no axis's speed changes
  by more than `amax × corner_s` across the corner.
* **Lookahead:** after every append the queue is re-planned backward, so the
  group can always stop by the end of what it has been given.
* **Execution** uses the same discrete stop law as a single axis, but toward
  the next segment's entry speed. Segments end exactly on their integer
  targets, and leftover travel carries into the next segment.
* **Arcs** (members 0 and 1) are fed in as chords, sized so no chord strays
  further than `tol` from the true circle. Chords are added lazily as the
  queue drains, so an arc of any length fits, and the last point is exact.
* **Hold/resume** decelerates along the path and waits. **Stop** holds, then
  drops the queue once at rest.

---

## 13. Streamed PVT

The host sends `(pos, vel, Δt)` points. Each axis follows a cubic Hermite
between them, landing exactly on each knot position and speed.
`PVT_START` starts only from rest, so several axes can start on the same
tick. If the queue runs dry while moving, the axis brakes at `amax` and
counts an **underrun** (reported as an event). PVT bypasses the s-curve
filters.

---

## 14. Electronic cams and virtual leaders

```mermaid
flowchart LR
    VL1["Virtual leader v1/v2<br/>(own trapezoid ramps)"] --> E
    AXL["or a real axis 1–10"] --> E
    E["cam_eval(table, leader.pos)"] --> PLUS(("+")) 
    OFF[offset] --> PLUS
    BL["engage blend<br/>(smoothstep fade)"] --> PLUS
    PLUS --> F[follower gen_pos<br/>unfiltered]
```

* A **table** holds up to 128 `(x, y)` points in full steps, joined by cubic
  Hermite segments with Catmull-Rom slopes, so it is C¹ and the follower's
  speed is continuous.
* **Cyclic** tables repeat with period `X`, and their net rise `R`
  accumulates each cycle (`R ≠ 0` advances the follower every revolution).
  Cycles are counted in exact integer units, so millions of cycles don't
  drift. **One-shot** tables hold their end values.
* Following is by **position**, so a follower retraces exactly when the
  leader reverses, at any speed.
* **Engage:** core 0 first checks (`cam_check`) that the follower can keep up
  with `v_f = y′·v_l` and `a_f = y″·v_l² + y′·a_l` at the leader's limits.
  This check is too slow for the 1 ms tick, so it doesn't run on core 1.
  Core 1 then fades out the initial position difference over `blend_ms`
  with a smoothstep.
* Two **virtual leaders** are pure trajectory generators with no motor:
  velocity, move, stop, limits and zero.
* There are 4 table slots. Tables are saved in flash by `save` and restored
  at boot.

---

## 15. Shows and the player

A **show** is a binary blob (compiled from JSON by `tools/stepperctl`) with
keyframe tracks for axes and LED pixels on one timeline. It is stored in one
of 4 flash slots, validated with a CRC and checked against the axes' limits.

```mermaid
sequenceDiagram
    participant FL as Flash slot
    participant P as player.c (core 0)
    participant Q as Command queue
    participant C1 as Core 1 axes
    participant L as WS2812
    FL->>P: show_parse
    P->>C1: MOVE to first keys (PREP), wait settled
    P->>Q: PVT points, keeps ~12 queued per axis, ≤16 per poll
    P->>Q: PVT_START (all show axes, same tick)
    loop RUN
        C1-->>P: snapshot pvt_depth
        P->>Q: top up points (round robin, wraps at loop seam)
        P->>L: LED colour = linear fade between keys
    end
```

Axis keys become PVT points, so motion passes exactly through every key.
Automatic speeds come from the neighbouring keys, with zero at the ends of a
non-looping show.

---

## 16. Safety

```mermaid
flowchart TD
    subgraph Ladder["Analog ladder on one ADC pin"]
        L1["3.3 V: e-stop open / cable cut → STOP"]
        L2["2.2 V: idle"]
        L3["1.3 V: Btn1"]
        L4["0.7 V: Btn2"]
        L5["0 V: driver nFAULT → STOP"]
    end
    ADC[ADC round robin, DMA] --> POLL[core 1 poll_ladder<br/>every 10 µs, also between PWM periods]
    POLL -->|3 consecutive stop samples| OFF["hbridge_safe_off all motors (coast)<br/>halt_all: axes, groups, cams<br/>~30 µs"]
    OFF --> LATCH[stop latched; motion commands dropped]
    LATCH -->|"CLEAR (c / Btn1), refused while line still reads stop"| RE[hbridge_restart, phase = pos, amp from 0]
    WD[core 0 watchdog:<br/>no core 1 heartbeat] --> OFF2[safe_off all motors]
```

* **Stop latency** is about 30 µs. The ladder is also polled inside the
  per-period loop, not just once per tick.
* **A held button can hide an open e-stop:** e-stop open + Btn1 reads
  1.65 V and e-stop open + Btn2 reads 0.82 V, both inside the button bands.
  The 1.49–1.76 V band, held for 5 ms, latches an e-stop. Btn2's case is too
  close to Btn2 alone to split, so any button held longer than 3 s latches
  an e-stop (this also catches a stuck button). Neither counts as a press,
  and the stop can't be cleared until the line is back to idle.
* **Core 1 watchdog:** core 0 watches `control_heartbeat`. If it stops (and
  no flash write is in progress), all outputs go to coast.
* **PIO starvation** fails to brake, as described in section 10.
* **Power-up:** the outputs run at zero amplitude until V5 has settled, then
  `control_energized` lets amplitude ramp up at the slew limit.
* **Flash writes** (config, shows, cams) pause core 1 safely through
  `flash_safe_execute`, and only with all axes at rest.

---

## 17. Configuration and persistence

| Item | Where |
|---|---|
| per-axis vmax, amax, profile, jerk_ms | `config_t`, two alternating flash sectors, generation counter + CRC-32 |
| drive curve (amp_low/high/hold, low/high speed), reverse, swap coils | `config_t` |
| hold delay, boot show | `config_t` |
| shows | 4 slots (`show_store.c`) |
| cam tables | `cam_store.c`, saved by `save` |

An interrupted save leaves the previous record valid. At load, the newest
valid record wins.

---

## 18. Interfaces

* **USB text console:** human commands (`m`, `j`, `g`, `gl`, `ga`, `p`, `cam`,
  `ce`, `vl`, `t`, `drive`, `save`, ...). Type `help`.
* **USB binary protocol:** COBS frames delimited by `0x00`, CRC-16. Frames
  share the port with the console, and every request is ACKed with the core 1
  sequence number (spec in `protocol.h`, client in `tools/stepperctl`).
* **I²C target** (Qwiic, address 0x42, RP2354B board): the same requests
  without framing. Untested.
* **Telemetry:** up to 1 kHz, numbered lines, with selectable axes and fields,
  plus events (done, underrun, e-stop, fault, clear).
* **Standalone mode:** a boot show starts at power-up. Btn1 clears a stop or
  starts/stops the show, and Btn2 selects the next show.
* **Status LEDs:** pixel 0 shows overall status (fault, watchdog, bypass),
  and pixels 1–10 show each axis's speed and direction.

---

## 19. Summary: life of one microstep

```mermaid
flowchart TD
    A["host: MOVE axis 3 → 500 steps"] --> B["core 0: control_post (seq N)"]
    B --> C["core 1, tick start: apply → motion_move_to"]
    C --> D["generate: stop law → gen_pos += (v+u)/2·dt"]
    D --> E["scurve moving average → pos += Δ"]
    E --> F["Δ/20 per PWM period → phase += step"]
    F --> G["LUT[phase>>22] → cos/sin × amp × 3738"]
    G --> H["error diffusion → integer duties ≥ 38 counts or 0"]
    H --> I["encode: 4 segments → 2 words"]
    I --> J["DMA ring → TX FIFO → PIO out pins"]
    J --> K["AT8833: drive / brake → coil current ∝ sin, cos"]
    K --> L["rotor follows the rotating field"]
```

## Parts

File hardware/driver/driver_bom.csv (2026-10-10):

Refs | Value | Footprint | Qty | MPN | LCSC | Note
C1,C4,C7,C10,C13,C16,C19,C22,C25,C28 | 1u | Capacitor_SMD:C_0402_1005Metric | 10 | CL05A105KA5NQNC | C52923
C2,C5,C8,C11,C14,C17,C20,C23,C26,C29,C34 | 100n | Capacitor_SMD:C_0402_1005Metric | 11 | CL05B104KO5NNNC | C1525
C3,C6,C9,C12,C15,C18,C21,C24,C27,C30 | 2.2u | Capacitor_SMD:C_0402_1005Metric | 10 | CL05A225KO5NQNC | C170151
C31,C32,C33 | 10u | Capacitor_SMD:C_0805_2012Metric | 3 | CL21A106KAYNNNE | C15850
J1 | BTB 40P socket | stack:Hirose_DF40C-2.0-40DS_Socket | 1 | DF40C(2.0)-40DS-0.4V(51) | C597934 | from controller A, top side
J2 | BTB 40P socket | stack:Hirose_DF40C-2.0-40DS_Socket | 1 | DF40C(2.0)-40DS-0.4V(51) | C597934 | from controller B, top side
J3 | BTB 40P header | stack:Hirose_DF40C-40DP_Header | 1 | DF40C-40DP-0.4V(51) | C424643 | to tier 3 A, board underside
J4 | BTB 40P header | stack:Hirose_DF40C-40DP_Header | 1 | DF40C-40DP-0.4V(51) | C424643 | to tier 3 B, board underside
R1,R2,R3,R4,R5,R6,R7,R8,R9,R10,R11,R12,R13,R14,R15,R16,R17,R18,R19,R20 | 0.82 | Resistor_SMD:R_0603_1608Metric | 20 | SR731JTTDR820F | C186570 | chops at 0.2-0.29 A (VTRIP 160-240 mV); Kelvin return
R21 | 47k | Resistor_SMD:R_0402_1005Metric | 1 | 0402WGF4702TCE | C25792
R22 | 39k 1% | Resistor_SMD:R_0402_1005Metric | 1 | 0402WGF3902TCE | C25783
R23 | 10k 1% | Resistor_SMD:R_0402_1005Metric | 1 | 0402WGF1002TCE | C25744
U1,U2,U3,U4,U5,U6,U7,U8,U9,U10 | AT8833CQ | Package_DFN_QFN:QFN-16-1EP_4x4mm_P0.65mm_EP2.1x2.1mm | 10 | AT8833CQ | C5120769 | DRV8833RTY pinout; 2nd source JSMSEMI DRV8833RTYR-JSM C55566425

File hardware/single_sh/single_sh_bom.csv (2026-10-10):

Refs | Value | Footprint | Qty | MPN | LCSC | Note
C1,C4,C7,C10,C13,C16,C19,C22,C25,C28,C53,C55,C59 | 1u | Capacitor_SMD:C_0402_1005Metric | 13 | CL05A105KA5NQNC | C52923
C2,C5,C8,C11,C14,C17,C20,C23,C26,C29,C34,C35,C36,C37,C38,C39,C40,C41,C42,C43,C45,C46,C47,C56,C57,C58,C60 | 100n | Capacitor_SMD:C_0402_1005Metric | 27 | CL05B104KO5NNNC | C1525
C3,C6,C9,C12,C15,C18,C21,C24,C27,C30 | 2.2u | Capacitor_SMD:C_0402_1005Metric | 10 | CL05A225KO5NQNC | C170151
C31,C32,C33,C52,C61 | 10u | Capacitor_SMD:C_0805_2012Metric | 5 | CL21A106KAYNNNE | C15850
C44,C48,C49 | 4.7u | Capacitor_SMD:C_0402_1005Metric | 3 | CL05A475MP5NRNC | C23733
C50,C51 | 15p | Capacitor_SMD:C_0402_1005Metric | 2 | 0402CG150J500NT | C1548
C54 | 100n | Capacitor_SMD:C_0402_1005Metric | 1 | CL05B104KO5NNNC | C1525 | soft-start timing with the 100k
D1,D3 | SS54 | Diode_SMD:D_SMA | 2 | SS54 | C22452 | MDD; Vf 0.55 V @ 5 A
D2 | XL-2020RGBC-WS2812B | LED_SMD:LED_WS2812B-2020_PLCC4_2.0x2.0mm | 1 | XL-2020RGBC-WS2812B | C5349955 | XINGLIGHT; WS2812B-2020 pinout and footprint; Worldsemi C965555 was out of stock at JLCPCB
F1 | 1.5A hold | Fuse:Fuse_1812_4532Metric | 1 | SMD1812P150TF/8 | C209721 | PTTC; 1.5 A hold / 3 A trip, 8 V; alt C21002
F2 | 1.5A hold | Fuse:Fuse_1812_4532Metric | 1 | SMD1812P150TF/8 | C209721 | PTTC; 1.5 A hold / 3 A trip, 8 V
J1 | USB-C | Connector_USB:USB_C_Receptacle_HRO_TYPE-C-31-M-12 | 1 | TYPE-C-31-M-12 | C165948 | THT shell legs; enclosure supports receptacle
J2,J3 | Qwiic | Connector_JST:JST_SH_BM04B-SRSS-TB_1x04-1MP_P1.00mm_Vertical | 2 | BM04B-SRSS-TB | C160390
J4 | 5V IN | Connector_JST:JST_PH_B2B-PH-K_1x02_P2.00mm_Vertical | 1 | B2B-PH-K-S | C131337
J5 | LED STRIP | Connector_JST:JST_XH_B3B-XH-A_1x03_P2.50mm_Vertical | 1 | B3B-XH-A | C144394
J6 | LED PWR | Connector_JST:JST_PH_B2B-PH-K_1x02_P2.00mm_Vertical | 1 | B2B-PH-K-S | C131337 | separate strip supply (optional)
J7 | E-STOP | Connector_JST:JST_PH_B2B-PH-K_1x02_P2.00mm_Vertical | 1 | B2B-PH-K-S | C131337
J8 | PANEL BTN | Connector_JST:JST_PH_B3B-PH-K_1x03_P2.00mm_Vertical | 1 | B3B-PH-K-S | C131339 | button from pin1 to pin2/pin3
J11 | M1+M2 | Connector_JST:JST_SH_BM08B-SRSS-TB_1x08-1MP_P1.00mm_Vertical | 1 | BM08B-SRSS-TB | C160394
J12 | M3+M4 | Connector_JST:JST_SH_BM08B-SRSS-TB_1x08-1MP_P1.00mm_Vertical | 1 | BM08B-SRSS-TB | C160394
J13 | M5+M6 | Connector_JST:JST_SH_BM08B-SRSS-TB_1x08-1MP_P1.00mm_Vertical | 1 | BM08B-SRSS-TB | C160394
J14 | M7+M8 | Connector_JST:JST_SH_BM08B-SRSS-TB_1x08-1MP_P1.00mm_Vertical | 1 | BM08B-SRSS-TB | C160394
J15 | M9+M10 | Connector_JST:JST_SH_BM08B-SRSS-TB_1x08-1MP_P1.00mm_Vertical | 1 | BM08B-SRSS-TB | C160394
L1 | 3.3u | Inductor_SMD:L_Cenker_CKCS201610 | 1 | AOTA-B201610S3R3-101-T | C42411119 | Abracon part per RP2350 design guide; 2016 size
Q1 | AO3401A | Package_TO_SOT_SMD:SOT-23 | 1 | AO3401A | C15127 | AOS; 60 mohm @ 4.5 V, Vth ~0.9 V
R1,R2,R3,R4,R5,R6,R7,R8,R9,R10,R11,R12,R13,R14,R15,R16,R17,R18,R19,R20 | 0.82 | Resistor_SMD:R_0603_1608Metric | 20 | SR731JTTDR820F | C186570 | chops at 0.2-0.29 A (VTRIP 160-240 mV); Kelvin return
R21 | 47k | Resistor_SMD:R_0402_1005Metric | 1 | 0402WGF4702TCE | C25792
R22 | 39k 1% | Resistor_SMD:R_0402_1005Metric | 1 | 0402WGF3902TCE | C25783
R23,R33,R34,R37,R40 | 10k 1% | Resistor_SMD:R_0402_1005Metric | 5 | 0402WGF1002TCE | C25744
R24,R38 | 33 | Resistor_SMD:R_0402_1005Metric | 2 | 0402WGF330JTCE | C25105
R25,R36 | 1k | Resistor_SMD:R_0402_1005Metric | 2 | 0402WGF1001TCE | C11702
R26,R27 | 27 | Resistor_SMD:R_0402_1005Metric | 2 | 0402WGF270JTCE | C25100
R28,R29 | 5.1k | Resistor_SMD:R_0402_1005Metric | 2 | 0402WGF5101TCE | C25905
R30 | 100k | Resistor_SMD:R_0402_1005Metric | 1 | 0402WGF1003TCE | C25741 | soft-start timing with the 100n
R31,R32 | 4.7k | Resistor_SMD:R_0402_1005Metric | 2 | 0402WGF4701TCE | C25900
R35,R41 | 3.3k 1% | Resistor_SMD:R_0402_1005Metric | 2 | 0402WGF3301TCE | C25890
R39 | 20k 1% | Resistor_SMD:R_0402_1005Metric | 1 | 0402WGF2002TCE | C25765
R42 | 4.7k | Resistor_SMD:R_0402_1005Metric | 1 | 0402WGF4701TCE | C25900 | board-ID level; 5% ok, see hardware/README.md
SW1 | BTN1 | Button_Switch_SMD:SW_SPST_TS-1088-xR020 | 1 | TS-1088-AR02016 | C720477 | XUNPU 3.9x3.0 mm 2-pad; small so the BTB fan-out routes
SW2 | BTN2 | Button_Switch_SMD:SW_SPST_TS-1088-xR020 | 1 | TS-1088-AR02016 | C720477 | XUNPU 3.9x3.0 mm 2-pad; small so the BTB fan-out routes
SW3 | BOOTSEL | Button_Switch_SMD:SW_SPST_TS-1088-xR020 | 1 | TS-1088-AR02016 | C720477 | XUNPU 3.9x3.0 mm 2-pad, same as BTN1/BTN2
U1,U2,U3,U4,U5,U6,U7,U8,U9,U10 | AT8833CQ | Package_DFN_QFN:QFN-16-1EP_4x4mm_P0.65mm_EP2.1x2.1mm | 10 | AT8833CQ | C5120769 | DRV8833RTY pinout; 2nd source JSMSEMI DRV8833RTYR-JSM C55566425
U11 | RP2354B | Package_DFN_QFN:QFN-80-1EP_10x10mm_P0.4mm_EP3.4x3.4mm | 1 | RP2354B | C39843328 | 2 MB in-package flash; leave QSPI_SD0-3/SCLK unconnected
U12 | TPD2E2U06 | Package_TO_SOT_SMD:SOT-553 | 1 | TPD2E2U06DRLR | C1972959 | TI; 1.5 pF; pins 1-2 NC
U13 | ME6211C33M5G | Package_TO_SOT_SMD:SOT-23-5 | 1 | ME6211C33M5G-N | C82942
U14,U15 | 74AHCT1G125 | Package_TO_SOT_SMD:SOT-23-5 | 2 | SN74AHCT1G125DBVR | C7484
Y1 | 12MHz | Crystal:Crystal_SMD_3225-4Pin_3.2x2.5mm | 1 | ABM8-272-T3 | C20625731 | Abracon, per RP2350 design guide; other crystals need retuning and testing

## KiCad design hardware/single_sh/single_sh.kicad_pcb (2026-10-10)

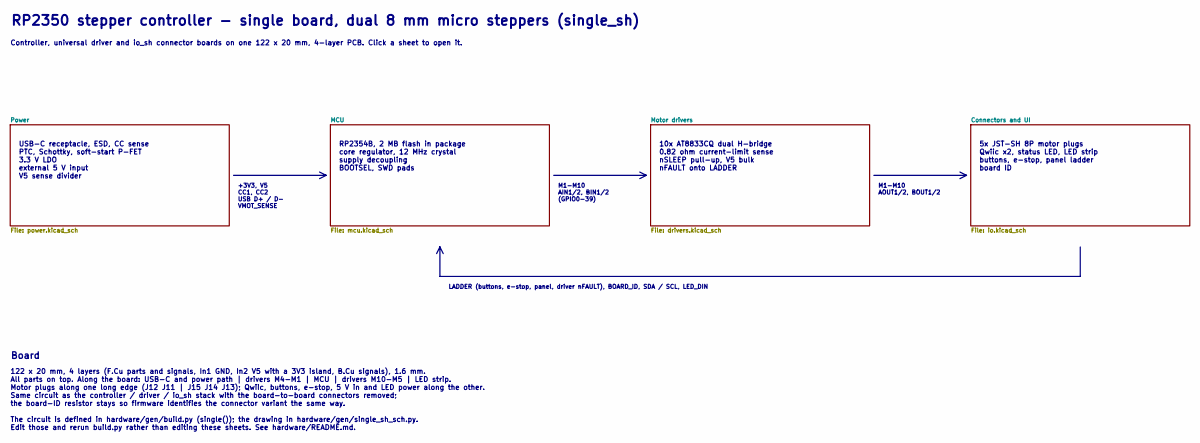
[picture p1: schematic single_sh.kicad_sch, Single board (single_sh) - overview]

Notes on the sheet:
RP2350 stepper controller - single board, dual 8 mm micro steppers (single_sh)
Controller, universal driver and io_sh connector boards on one 122 x 20 mm, 4-layer PCB. Click a sheet to open it.
USB-C receptacle, ESD, CC sense PTC, Schottky, soft-start P-FET 3.3 V LDO external 5 V input V5 sense divider
RP2354B, 2 MB flash in package core regulator, 12 MHz crystal supply decoupling BOOTSEL, SWD pads
10x AT8833CQ dual H-bridge 0.82 ohm current-limit sense nSLEEP pull-up, V5 bulk nFAULT onto LADDER
5x JST-SH 8P motor plugs Qwiic x2, status LED, LED strip buttons, e-stop, panel ladder board ID
+3V3, V5 CC1, CC2 USB D+ / D- VMOT_SENSE
M1-M10 AIN1/2, BIN1/2 (GPIO0-39)
M1-M10 AOUT1/2, BOUT1/2
LADDER (buttons, e-stop, panel, driver nFAULT), BOARD_ID, SDA / SCL, LED_DIN
Board
122 x 20 mm, 4 layers (F.Cu parts and signals, In1 GND, In2 V5 with a 3V3 island, B.Cu signals), 1.6 mm. All parts on top. Along the board: USB-C and power path | drivers M4-M1 | MCU | drivers M10-M5 | LED strip. Motor plugs along one long edge (J12 J11 | J15 J14 J13); Qwiic, buttons, e-stop, 5 V i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

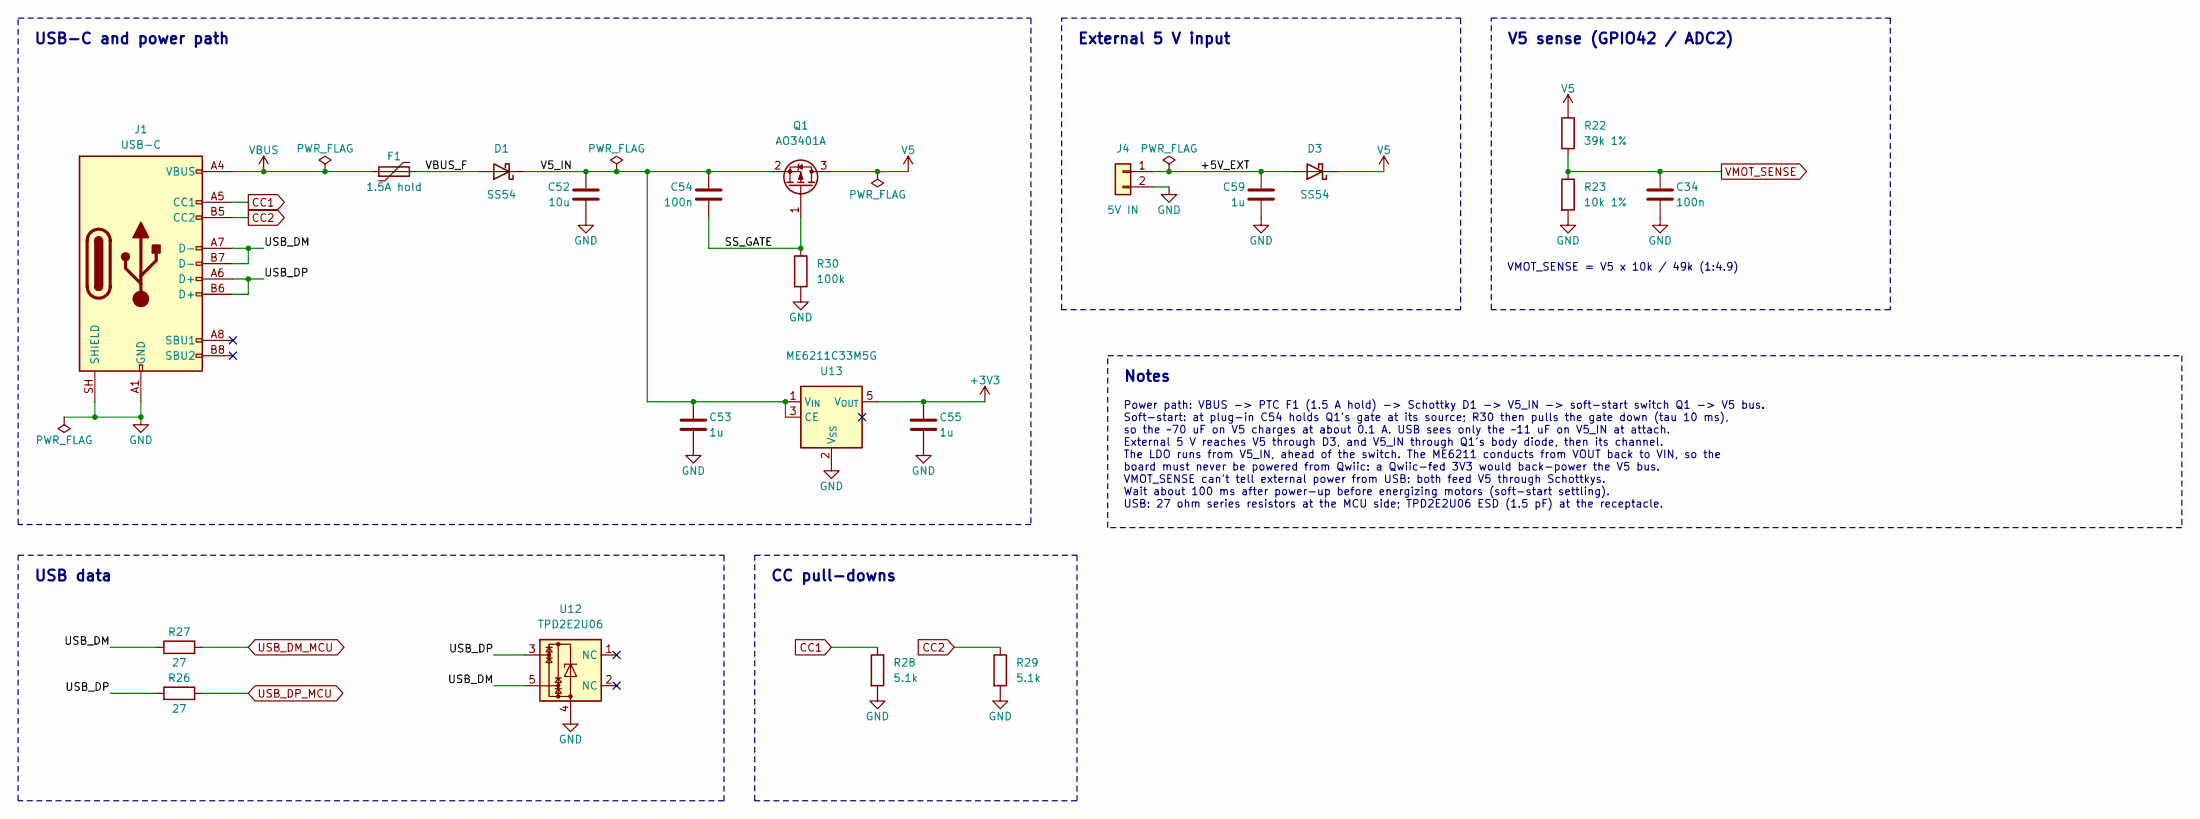
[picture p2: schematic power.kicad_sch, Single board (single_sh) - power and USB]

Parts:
C34, C54: 100n; C_0402_1005Metric; MPN CL05B104KO5NNNC; LCSC C1525
C52: 10u; C_0805_2012Metric; MPN CL21A106KAYNNNE; LCSC C15850
C53, C55, C59: 1u; C_0402_1005Metric; MPN CL05A105KA5NQNC; LCSC C52923
D1, D3: SS54; D_SMA; MPN SS54; LCSC C22452
F1: 1.5A hold; Fuse_1812_4532Metric; MPN SMD1812P150TF/8; LCSC C209721
J1: USB-C; USB_C_Receptacle_HRO_TYPE-C-31-M-12; MPN TYPE-C-31-M-12; LCSC C165948
J4: 5V IN; JST_PH_B2B-PH-K_1x02_P2.00mm_Vertical; MPN B2B-PH-K-S; LCSC C131337
Q1: AO3401A; SOT-23; MPN AO3401A; LCSC C15127
R22: 39k 1%; R_0402_1005Metric; MPN 0402WGF3902TCE; LCSC C25783
R23: 10k 1%; R_0402_1005Metric; MPN 0402WGF1002TCE; LCSC C25744
R26, R27: 27; R_0402_1005Metric; MPN 0402WGF270JTCE; LCSC C25100
R28, R29: 5.1k; R_0402_1005Metric; MPN 0402WGF5101TCE; LCSC C25905
R30: 100k; R_0402_1005Metric; MPN 0402WGF1003TCE; LCSC C25741
U12: TPD2E2U06; SOT-553; MPN TPD2E2U06DRLR; LCSC C1972959
U13: ME6211C33M5G; SOT-23-5; MPN ME6211C33M5G-N; LCSC C82942

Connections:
+3V3: C55.1, U13.5 (V_{OUT}); also elsewhere on the board
/Power/+5V_EXT: C59.1, D3.2 (A), J4.1
/Power/SS_GATE: C54.2, Q1.1 (G), R30.1
/Power/USB_DM: J1.A7 (D-), J1.B7 (D-), R27.1, U12.5
/Power/USB_DP: J1.A6 (D+), J1.B6 (D+), R26.1, U12.3
/Power/V5_IN: C52.1, C53.1, C54.1, D1.1 (K), Q1.2 (S), U13.1 (V_{IN}), U13.3 (CE)
/Power/VBUS_F: D1.2 (A), F1.2
CC1: J1.A5 (CC1), R28.1; also elsewhere on the board
CC2: J1.B5 (CC2), R29.1; also elsewhere on the board
GND: C34.2, C52.2, C53.2, C55.2, C59.2, J1.A1 (GND), J1.A12 (GND), J1.B1 (GND), J1.B12 (GND), J1.SH (SHIELD), J4.2, R23.2, R28.2, R29.2, R30.2, U12.4, U13.2 (V_{SS}); also elsewhere on the board
USB_DM_MCU: R27.2; also elsewhere on the board
USB_DP_MCU: R26.2; also elsewhere on the board
V5: D3.1 (K), Q1.3 (D), R22.1; also elsewhere on the board
VBUS: F1.1, J1.A4 (VBUS), J1.A9 (VBUS), J1.B4 (VBUS), J1.B9 (VBUS)
VMOT_SENSE: C34.1, R22.2, R23.1; also elsewhere on the board

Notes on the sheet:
USB-C and power path
USB data
CC pull-downs
External 5 V input
V5 sense (GPIO42 / ADC2)
VMOT_SENSE = V5 x 10k / 49k (1:4.9)
Notes
Power path: VBUS -> PTC F1 (1.5 A hold) -> Schottky D1 -> V5_IN -> soft-start switch Q1 -> V5 bus. Soft-start: at plug-in C54 holds Q1's gate at its source; R30 then pulls the gate down (tau 10 ms), so the ~70 uF on V5 charges at about 0.1 A. USB sees only the ~11 uF on V5_IN at attach. External 5 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

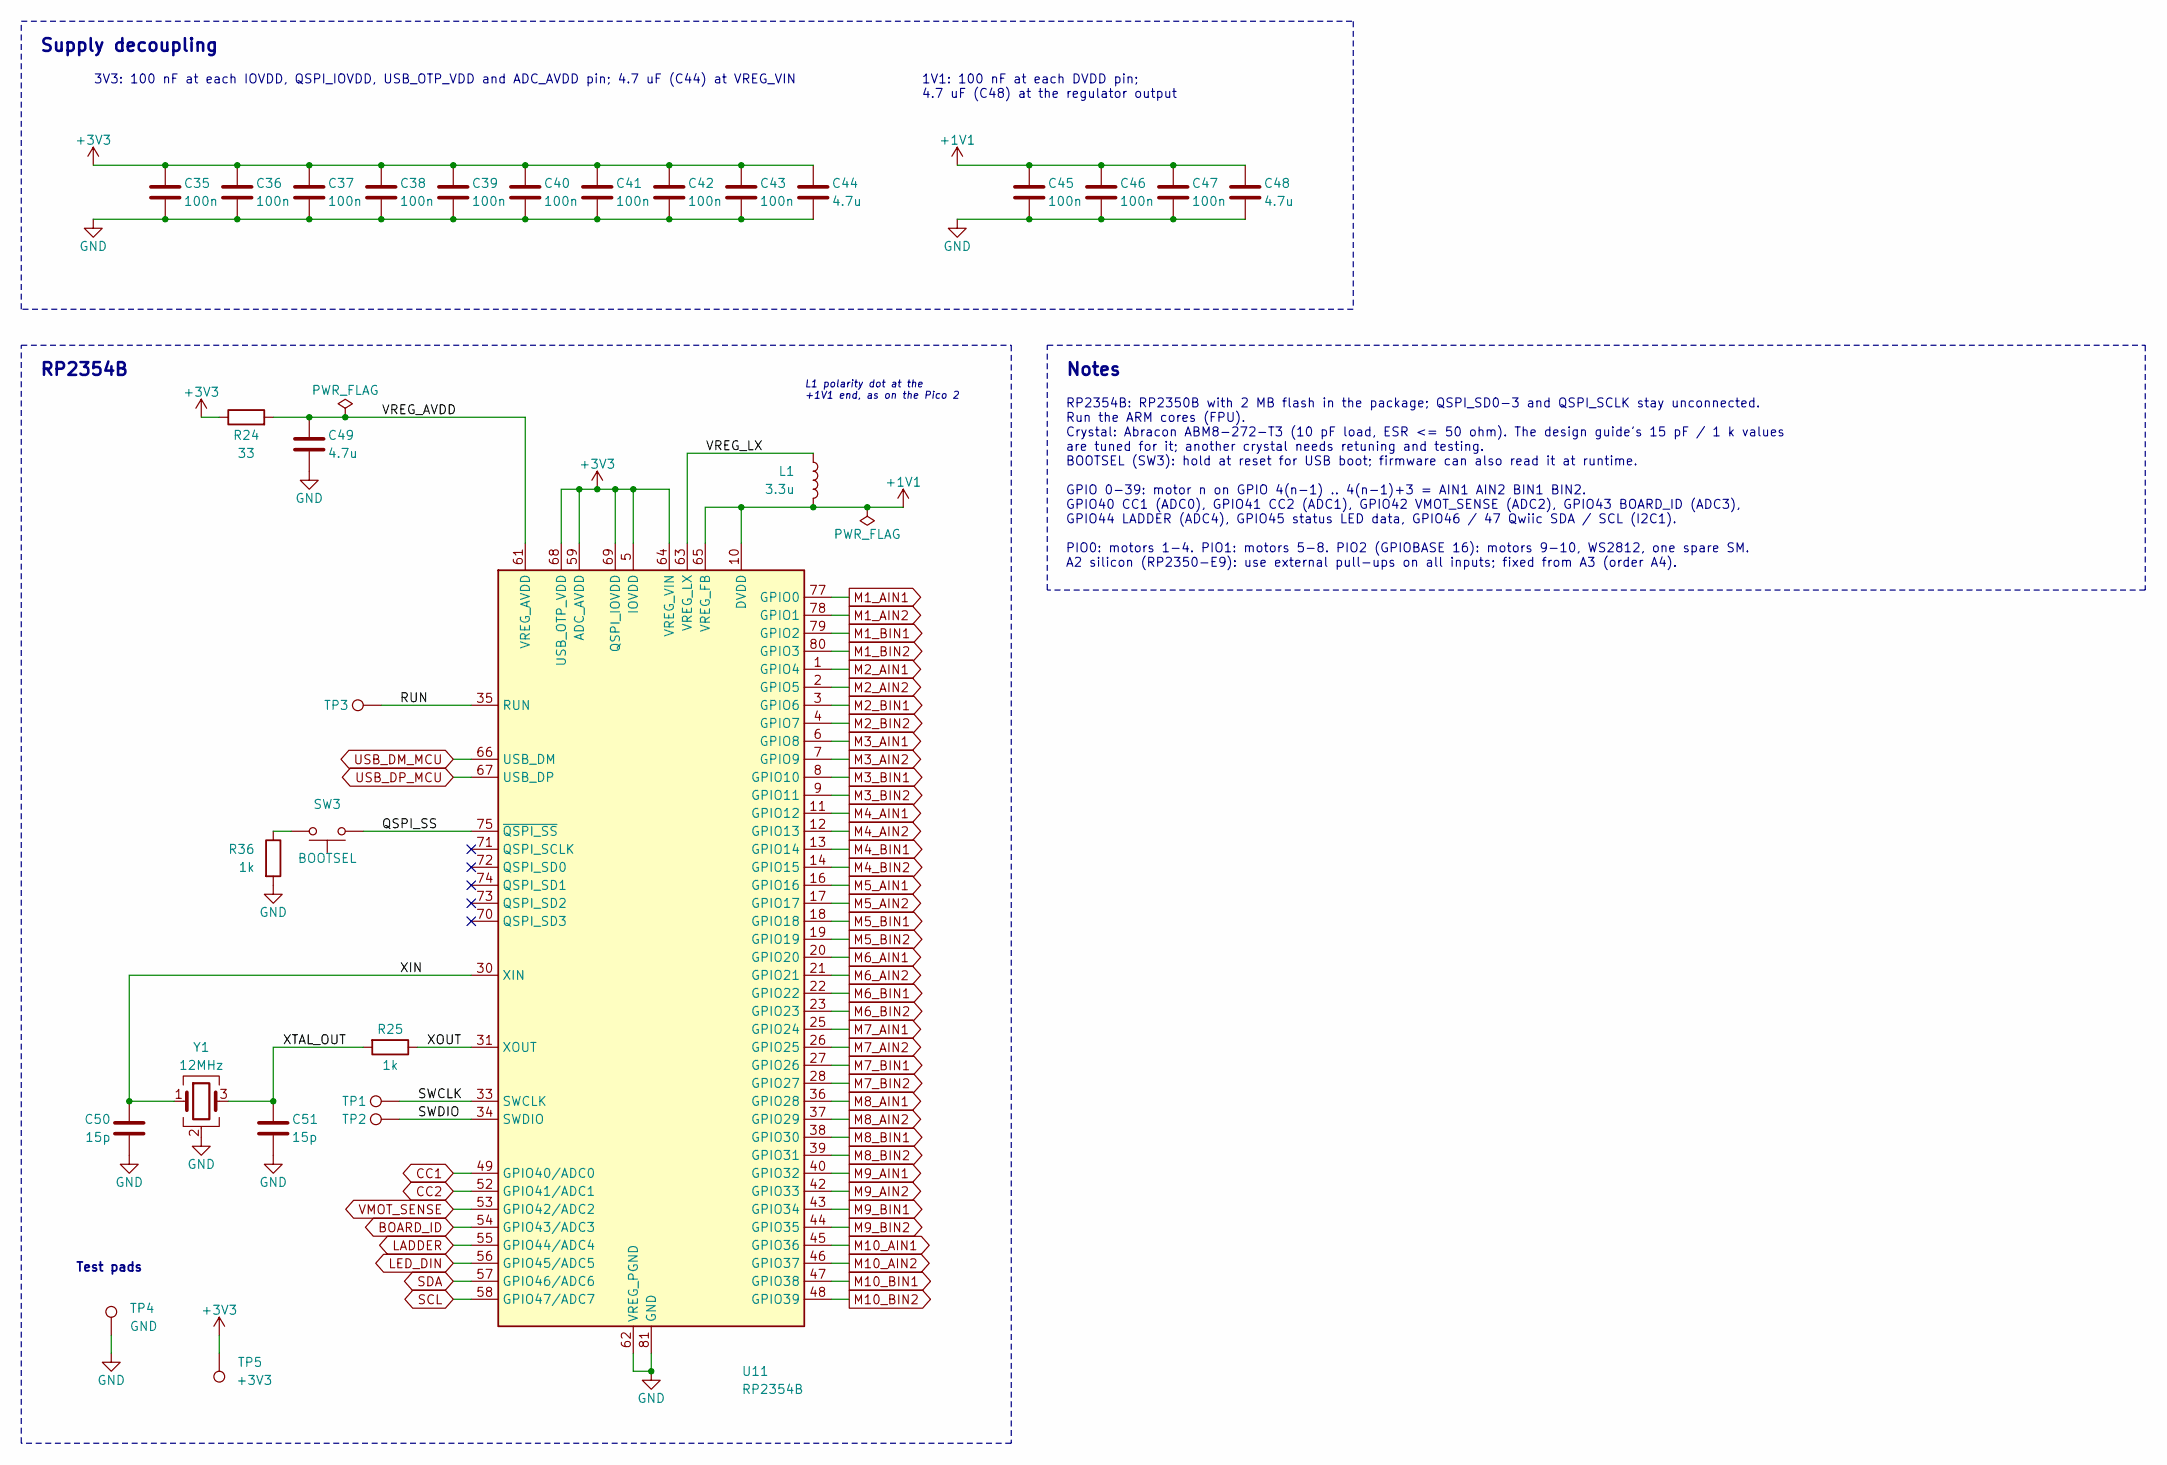
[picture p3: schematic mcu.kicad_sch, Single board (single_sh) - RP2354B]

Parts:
C35, C36, C37, C38, C39, C40, C41, C42, C43, C45, C46, C47: 100n; C_0402_1005Metric; MPN CL05B104KO5NNNC; LCSC C1525
C44, C48, C49: 4.7u; C_0402_1005Metric; MPN CL05A475MP5NRNC; LCSC C23733
C50, C51: 15p; C_0402_1005Metric; MPN 0402CG150J500NT; LCSC C1548
L1: 3.3u; L_Cenker_CKCS201610; MPN AOTA-B201610S3R3-101-T; LCSC C42411119
R24: 33; R_0402_1005Metric; MPN 0402WGF330JTCE; LCSC C25105
R25, R36: 1k; R_0402_1005Metric; MPN 0402WGF1001TCE; LCSC C11702
SW3: BOOTSEL; SW_SPST_TS-1088-xR020; MPN TS-1088-AR02016; LCSC C720477
TP1: SWCLK; TestPoint_Pad_D1.0mm
TP2: SWDIO; TestPoint_Pad_D1.0mm
TP3: RUN; TestPoint_Pad_D1.0mm
TP4: GND; TestPoint_Pad_D1.0mm
TP5: +3V3; TestPoint_Pad_D1.0mm
U11: RP2354B; QFN-80-1EP_10x10mm_P0.4mm_EP3.4x3.4mm; MPN RP2354B; LCSC C39843328
Y1: 12MHz; Crystal_SMD_3225-4Pin_3.2x2.5mm; MPN ABM8-272-T3; LCSC C20625731

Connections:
+1V1: C45.1, C46.1, C47.1, C48.1, L1.2, U11.10 (DVDD), U11.32 (DVDD), U11.51 (DVDD), U11.65 (VREG_FB)
+3V3: C35.1, C36.1, C37.1, C38.1, C39.1, C40.1, C41.1, C42.1, C43.1, C44.1, R24.1, TP5.1, U11.5 (IOVDD), U11.15 (IOVDD), U11.24 (IOVDD), U11.29 (IOVDD), U11.41 (IOVDD), U11.50 (IOVDD), U11.59 (ADC_AVDD), U11.60 (IOVDD), U11.64 (VREG_VIN), U11.68 (USB_OTP_VDD), U11.69 (QSPI_IOVDD), U11.76 (IOVDD); also elsewhere on the board
/MCU/QSPI_SS: SW3.1, U11.75 (~QSPI_SS)
/MCU/RUN: TP3.1, U11.35 (RUN)
/MCU/SWCLK: TP1.1, U11.33 (SWCLK)
/MCU/SWDIO: TP2.1, U11.34 (SWDIO)
/MCU/VREG_AVDD: C49.1, R24.2, U11.61 (VREG_AVDD)
/MCU/VREG_LX: L1.1, U11.63 (VREG_LX)
/MCU/XIN: C50.1, U11.30 (XIN), Y1.1
/MCU/XOUT: R25.1, U11.31 (XOUT)
/MCU/XTAL_OUT: C51.1, R25.2, Y1.3
BOARD_ID: U11.54 (GPIO43/ADC3); also elsewhere on the board
CC1: U11.49 (GPIO40/ADC0); also elsewhere on the board
CC2: U11.52 (GPIO41/ADC1); also elsewhere on the board
GND: C35.2, C36.2, C37.2, C38.2, C39.2, C40.2, C41.2, C42.2, C43.2, C44.2, C45.2, C46.2, C47.2, C48.2, C49.2, C50.2, C51.2, R36.2, TP4.1, U11.62 (VREG_PGND), U11.81 (GND), Y1.2 (G), Y1.4 (G); also elsewhere on the board
LADDER: U11.55 (GPIO44/ADC4); also elsewhere on the board
LED_DIN: U11.56 (GPIO45/ADC5); also elsewhere on the board
M1_AIN1: U11.77 (GPIO0); also elsewhere on the board
M1_AIN2: U11.78 (GPIO1); also elsewhere on the board
M1_BIN1: U11.79 (GPIO2); also elsewhere on the board
M1_BIN2: U11.80 (GPIO3); also elsewhere on the board
M2_AIN1: U11.1 (GPIO4); also elsewhere on the board
M2_AIN2: U11.2 (GPIO5); also elsewhere on the board
M2_BIN1: U11.3 (GPIO6); also elsewhere on the board
M2_BIN2: U11.4 (GPIO7); also elsewhere on the board
M3_AIN1: U11.6 (GPIO8); also elsewhere on the board
M3_AIN2: U11.7 (GPIO9); also elsewhere on the board
M3_BIN1: U11.8 (GPIO10); also elsewhere on the board
M3_BIN2: U11.9 (GPIO11); also elsewhere on the board
M4_AIN1: U11.11 (GPIO12); also elsewhere on the board
M4_AIN2: U11.12 (GPIO13); also elsewhere on the board
M4_BIN1: U11.13 (GPIO14); also elsewhere on the board
M4_BIN2: U11.14 (GPIO15); also elsewhere on the board
M5_AIN1: U11.16 (GPIO16); also elsewhere on the board
M5_AIN2: U11.17 (GPIO17); also elsewhere on the board
M5_BIN1: U11.18 (GPIO18); also elsewhere on the board
M5_BIN2: U11.19 (GPIO19); also elsewhere on the board
M6_AIN1: U11.20 (GPIO20); also elsewhere on the board
M6_AIN2: U11.21 (GPIO21); also elsewhere on the board
M6_BIN1: U11.22 (GPIO22); also elsewhere on the board
M6_BIN2: U11.23 (GPIO23); also elsewhere on the board
M7_AIN1: U11.25 (GPIO24); also elsewhere on the board
M7_AIN2: U11.26 (GPIO25); also elsewhere on the board
M7_BIN1: U11.27 (GPIO26); also elsewhere on the board
M7_BIN2: U11.28 (GPIO27); also elsewhere on the board
M8_AIN1: U11.36 (GPIO28); also elsewhere on the board
M8_AIN2: U11.37 (GPIO29); also elsewhere on the board
M8_BIN1: U11.38 (GPIO30); also elsewhere on the board
M8_BIN2: U11.39 (GPIO31); also elsewhere on the board
M9_AIN1: U11.40 (GPIO32); also elsewhere on the board
M9_AIN2: U11.42 (GPIO33); also elsewhere on the board
M9_BIN1: U11.43 (GPIO34); also elsewhere on the board
M9_BIN2: U11.44 (GPIO35); also elsewhere on the board
M10_AIN1: U11.45 (GPIO36); also elsewhere on the board
M10_AIN2: U11.46 (GPIO37); also elsewhere on the board
M10_BIN1: U11.47 (GPIO38); also elsewhere on the board
M10_BIN2: U11.48 (GPIO39); also elsewhere on the board
unnamed: R36.1, SW3.2
SCL: U11.58 (GPIO47/ADC7); also elsewhere on the board
SDA: U11.57 (GPIO46/ADC6); also elsewhere on the board
USB_DM_MCU: U11.66 (USB_DM); also elsewhere on the board
USB_DP_MCU: U11.67 (USB_DP); also elsewhere on the board
VMOT_SENSE: U11.53 (GPIO42/ADC2); also elsewhere on the board

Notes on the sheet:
RP2354B
L1 polarity dot at the +1V1 end, as on the Pico 2
Supply decoupling
3V3: 100 nF at each IOVDD, QSPI_IOVDD, USB_OTP_VDD and ADC_AVDD pin; 4.7 uF (C44) at VREG_VIN
1V1: 100 nF at each DVDD pin; 4.7 uF (C48) at the regulator output
Test pads
Notes
RP2354B: RP2350B with 2 MB flash in the package; QSPI_SD0-3 and QSPI_SCLK stay unconnected. Run the ARM cores (FPU). Crystal: Abracon ABM8-272-T3 (10 pF load, ESR <= 50 ohm). The design guide's 15 pF / 1 k values are tuned for it; another crystal needs retuning and testing. BOOTSEL (SW3): hold at r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

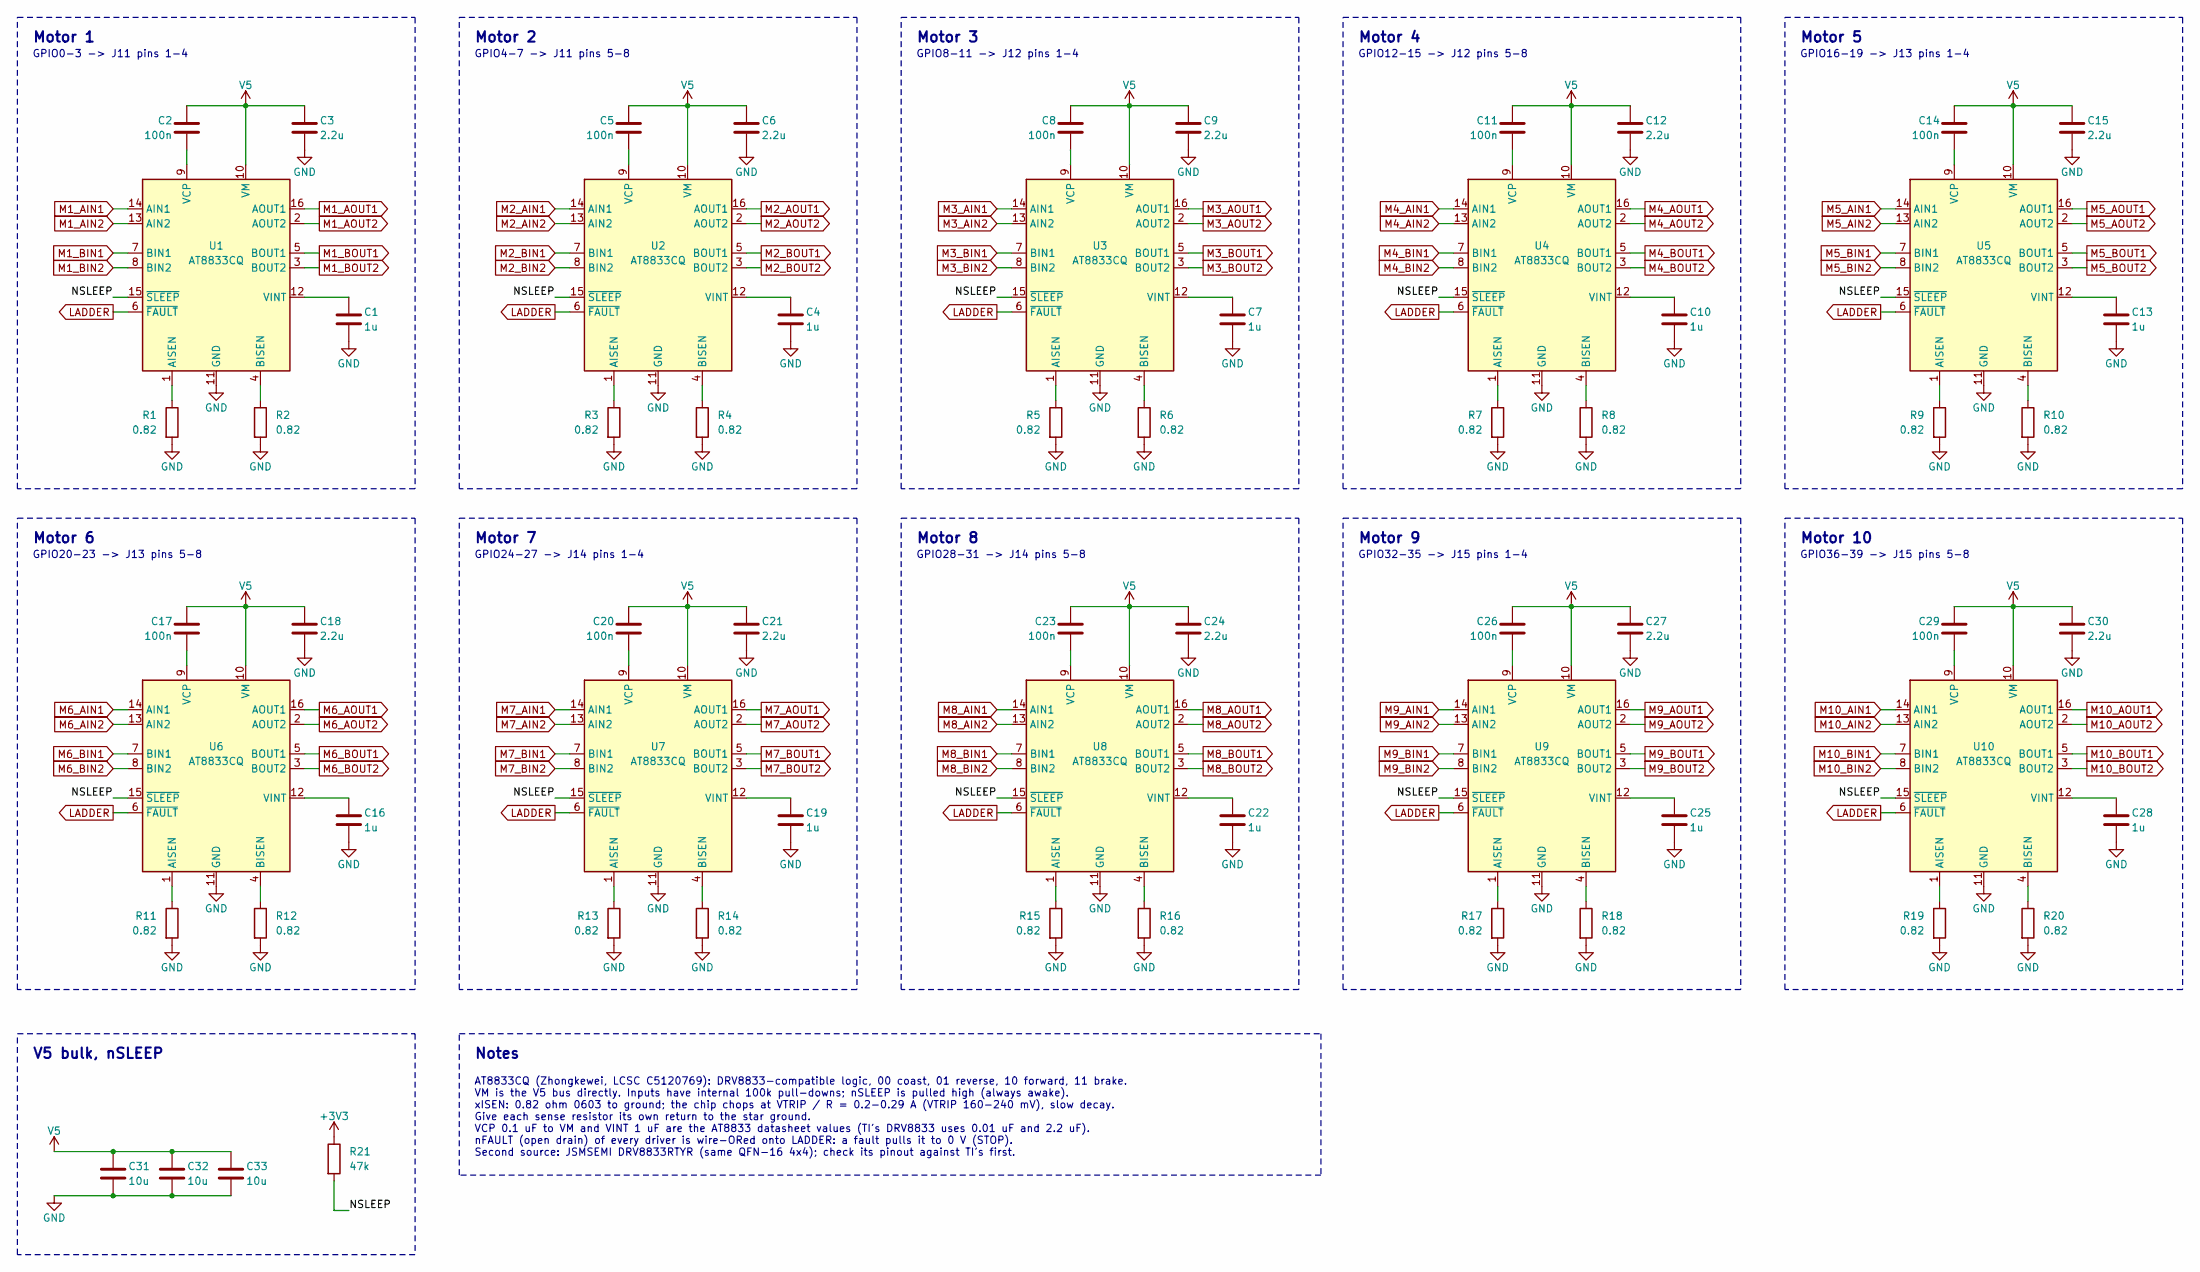
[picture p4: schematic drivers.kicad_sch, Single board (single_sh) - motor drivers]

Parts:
C1, C4, C7, C10, C13, C16, C19, C22, C25, C28: 1u; C_0402_1005Metric; MPN CL05A105KA5NQNC; LCSC C52923
C2, C5, C8, C11, C14, C17, C20, C23, C26, C29: 100n; C_0402_1005Metric; MPN CL05B104KO5NNNC; LCSC C1525
C3, C6, C9, C12, C15, C18, C21, C24, C27, C30: 2.2u; C_0402_1005Metric; MPN CL05A225KO5NQNC; LCSC C170151
C31, C32, C33: 10u; C_0805_2012Metric; MPN CL21A106KAYNNNE; LCSC C15850
R1, R2, R3, R4, R5, R6, R7, R8, R9, R10, R11, R12, R13, R14, R15, R16, R17, R18, R19, R20: 0.82; R_0603_1608Metric; MPN SR731JTTDR820F; LCSC C186570
R21: 47k; R_0402_1005Metric; MPN 0402WGF4702TCE; LCSC C25792
U1, U2, U3, U4, U5, U6, U7, U8, U9, U10: AT8833CQ; QFN-16-1EP_4x4mm_P0.65mm_EP2.1x2.1mm; MPN AT8833CQ; LCSC C5120769

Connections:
+3V3: R21.1; also elsewhere on the board
/Motor drivers/NSLEEP: R21.2, U1.15 (~SLEEP), U2.15 (~SLEEP), U3.15 (~SLEEP), U4.15 (~SLEEP), U5.15 (~SLEEP), U6.15 (~SLEEP), U7.15 (~SLEEP), U8.15 (~SLEEP), U9.15 (~SLEEP), U10.15 (~SLEEP)
GND: C1.2, C3.2, C4.2, C6.2, C7.2, C9.2, C10.2, C12.2, C13.2, C15.2, C16.2, C18.2, C19.2, C21.2, C22.2, C24.2, C25.2, C27.2, C28.2, C30.2, C31.2, C32.2, C33.2, R1.2, R2.2, R3.2, R4.2, R5.2, R6.2, R7.2, R8.2, R9.2, R10.2, R11.2, R12.2, R13.2, R14.2, R15.2, R16.2, R17.2, R18.2, R19.2, R20.2, U1.11 (GND), U1.17 (GND), U2.11 (GND), U2.17 (GND), U3.11 (GND), U3.17 (GND), U4.11 (GND), U4.17 (GND), U5.11 (GND), U5.17 (GND), U6.11 (GND), U6.17 (GND), U7.11 (GND), U7.17 (GND), U8.11 (GND), U8.17 (GND), U9.11 (GND), U9.17 (GND), U10.11 (GND), U10.17 (GND); also elsewhere on the board
LADDER: U1.6 (~FAULT), U2.6 (~FAULT), U3.6 (~FAULT), U4.6 (~FAULT), U5.6 (~FAULT), U6.6 (~FAULT), U7.6 (~FAULT), U8.6 (~FAULT), U9.6 (~FAULT), U10.6 (~FAULT); also elsewhere on the board
M1_AIN1: U1.14 (AIN1); also elsewhere on the board
M1_AIN2: U1.13 (AIN2); also elsewhere on the board
M1_AOUT1: U1.16 (AOUT1); also elsewhere on the board
M1_AOUT2: U1.2 (AOUT2); also elsewhere on the board
M1_BIN1: U1.7 (BIN1); also elsewhere on the board
M1_BIN2: U1.8 (BIN2); also elsewhere on the board
M1_BOUT1: U1.5 (BOUT1); also elsewhere on the board
M1_BOUT2: U1.3 (BOUT2); also elsewhere on the board
M2_AIN1: U2.14 (AIN1); also elsewhere on the board
M2_AIN2: U2.13 (AIN2); also elsewhere on the board
M2_AOUT1: U2.16 (AOUT1); also elsewhere on the board
M2_AOUT2: U2.2 (AOUT2); also elsewhere on the board
M2_BIN1: U2.7 (BIN1); also elsewhere on the board
M2_BIN2: U2.8 (BIN2); also elsewhere on the board
M2_BOUT1: U2.5 (BOUT1); also elsewhere on the board
M2_BOUT2: U2.3 (BOUT2); also elsewhere on the board
M3_AIN1: U3.14 (AIN1); also elsewhere on the board
M3_AIN2: U3.13 (AIN2); also elsewhere on the board
M3_AOUT1: U3.16 (AOUT1); also elsewhere on the board
M3_AOUT2: U3.2 (AOUT2); also elsewhere on the board
M3_BIN1: U3.7 (BIN1); also elsewhere on the board
M3_BIN2: U3.8 (BIN2); also elsewhere on the board
M3_BOUT1: U3.5 (BOUT1); also elsewhere on the board
M3_BOUT2: U3.3 (BOUT2); also elsewhere on the board
M4_AIN1: U4.14 (AIN1); also elsewhere on the board
M4_AIN2: U4.13 (AIN2); also elsewhere on the board
M4_AOUT1: U4.16 (AOUT1); also elsewhere on the board
M4_AOUT2: U4.2 (AOUT2); also elsewhere on the board
M4_BIN1: U4.7 (BIN1); also elsewhere on the board
M4_BIN2: U4.8 (BIN2); also elsewhere on the board
M4_BOUT1: U4.5 (BOUT1); also elsewhere on the board
M4_BOUT2: U4.3 (BOUT2); also elsewhere on the board
M5_AIN1: U5.14 (AIN1); also elsewhere on the board
M5_AIN2: U5.13 (AIN2); also elsewhere on the board
M5_AOUT1: U5.16 (AOUT1); also elsewhere on the board
M5_AOUT2: U5.2 (AOUT2); also elsewhere on the board
M5_BIN1: U5.7 (BIN1); also elsewhere on the board
M5_BIN2: U5.8 (BIN2); also elsewhere on the board
M5_BOUT1: U5.5 (BOUT1); also elsewhere on the board
M5_BOUT2: U5.3 (BOUT2); also elsewhere on the board
M6_AIN1: U6.14 (AIN1); also elsewhere on the board
M6_AIN2: U6.13 (AIN2); also elsewhere on the board
M6_AOUT1: U6.16 (AOUT1); also elsewhere on the board
M6_AOUT2: U6.2 (AOUT2); also elsewhere on the board
M6_BIN1: U6.7 (BIN1); also elsewhere on the board
M6_BIN2: U6.8 (BIN2); also elsewhere on the board
M6_BOUT1: U6.5 (BOUT1); also elsewhere on the board
M6_BOUT2: U6.3 (BOUT2); also elsewhere on the board
M7_AIN1: U7.14 (AIN1); also elsewhere on the board
M7_AIN2: U7.13 (AIN2); also elsewhere on the board
M7_AOUT1: U7.16 (AOUT1); also elsewhere on the board
M7_AOUT2: U7.2 (AOUT2); also elsewhere on the board
M7_BIN1: U7.7 (BIN1); also elsewhere on the board
M7_BIN2: U7.8 (BIN2); also elsewhere on the board
M7_BOUT1: U7.5 (BOUT1); also elsewhere on the board
M7_BOUT2: U7.3 (BOUT2); also elsewhere on the board
M8_AIN1: U8.14 (AIN1); also elsewhere on the board
M8_AIN2: U8.13 (AIN2); also elsewhere on the board
M8_AOUT1: U8.16 (AOUT1); also elsewhere on the board
M8_AOUT2: U8.2 (AOUT2); also elsewhere on the board
M8_BIN1: U8.7 (BIN1); also elsewhere on the board
M8_BIN2: U8.8 (BIN2); also elsewhere on the board
M8_BOUT1: U8.5 (BOUT1); also elsewhere on the board
M8_BOUT2: U8.3 (BOUT2); also elsewhere on the board
M9_AIN1: U9.14 (AIN1); also elsewhere on the board
M9_AIN2: U9.13 (AIN2); also elsewhere on the board
M9_AOUT1: U9.16 (AOUT1); also elsewhere on the board
M9_AOUT2: U9.2 (AOUT2); also elsewhere on the board
M9_BIN1: U9.7 (BIN1); also elsewhere on the board
M9_BIN2: U9.8 (BIN2); also elsewhere on the board
M9_BOUT1: U9.5 (BOUT1); also elsewhere on the board
M9_BOUT2: U9.3 (BOUT2); also elsewhere on the board
M10_AIN1: U10.14 (AIN1); also elsewhere on the board
M10_AIN2: U10.13 (AIN2); also elsewhere on the board
M10_AOUT1: U10.16 (AOUT1); also elsewhere on the board
M10_AOUT2: U10.2 (AOUT2); also elsewhere on the board
M10_BIN1: U10.7 (BIN1); also elsewhere on the board
M10_BIN2: U10.8 (BIN2); also elsewhere on the board
M10_BOUT1: U10.5 (BOUT1); also elsewhere on the board
M10_BOUT2: U10.3 (BOUT2); also elsewhere on the board
unnamed: R1.1, U1.1 (AISEN)
unnamed: R2.1, U1.4 (BISEN)
unnamed: C2.1, U1.9 (VCP)
unnamed: C1.1, U1.12 (VINT)
unnamed: R3.1, U2.1 (AISEN)
unnamed: R4.1, U2.4 (BISEN)
unnamed: C5.1, U2.9 (VCP)
unnamed: C4.1, U2.12 (VINT)
unnamed: R5.1, U3.1 (AISEN)
unnamed: R6.1, U3.4 (BISEN)
unnamed: C8.1, U3.9 (VCP)
unnamed: C7.1, U3.12 (VINT)
unnamed: R7.1, U4.1 (AISEN)
unnamed: R8.1, U4.4 (BISEN)
unnamed: C11.1, U4.9 (VCP)
unnamed: C10.1, U4.12 (VINT)
unnamed: R9.1, U5.1 (AISEN)
unnamed: R10.1, U5.4 (BISEN)
unnamed: C14.1, U5.9 (VCP)
unnamed: C13.1, U5.12 (VINT)
unnamed: R11.1, U6.1 (AISEN)
unnamed: R12.1, U6.4 (BISEN)
unnamed: C17.1, U6.9 (VCP)
unnamed: C16.1, U6.12 (VINT)
unnamed: R13.1, U7.1 (AISEN)
unnamed: R14.1, U7.4 (BISEN)
unnamed: C20.1, U7.9 (VCP)
unnamed: C19.1, U7.12 (VINT)
unnamed: R15.1, U8.1 (AISEN)
unnamed: R16.1, U8.4 (BISEN)
unnamed: C23.1, U8.9 (VCP)
unnamed: C22.1, U8.12 (VINT)
unnamed: R17.1, U9.1 (AISEN)
unnamed: R18.1, U9.4 (BISEN)
unnamed: C26.1, U9.9 (VCP)
unnamed: C25.1, U9.12 (VINT)
unnamed: R19.1, U10.1 (AISEN)
unnamed: R20.1, U10.4 (BISEN)
unnamed: C29.1, U10.9 (VCP)
unnamed: C28.1, U10.12 (VINT)
V5: C2.2, C3.1, C5.2, C6.1, C8.2, C9.1, C11.2, C12.1, C14.2, C15.1, C17.2, C18.1, C20.2, C21.1, C23.2, C24.1, C26.2, C27.1, C29.2, C30.1, C31.1, C32.1, C33.1, U1.10 (VM), U2.10 (VM), U3.10 (VM), U4.10 (VM), U5.10 (VM), U6.10 (VM), U7.10 (VM), U8.10 (VM), U9.10 (VM), U10.10 (VM); also elsewhere on the board

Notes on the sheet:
Motor 1
GPIO0-3 -> J11 pins 1-4
Motor 2
GPIO4-7 -> J11 pins 5-8
Motor 3
GPIO8-11 -> J12 pins 1-4
Motor 4
GPIO12-15 -> J12 pins 5-8
Motor 5
GPIO16-19 -> J13 pins 1-4
Motor 6
GPIO20-23 -> J13 pins 5-8
Motor 7
GPIO24-27 -> J14 pins 1-4
Motor 8
GPIO28-31 -> J14 pins 5-8
Motor 9
GPIO32-35 -> J15 pins 1-4
Motor 10
GPIO36-39 -> J15 pins 5-8
V5 bulk, nSLEEP
Notes
AT8833CQ (Zhongkewei, LCSC C5120769): DRV8833-compatible logic, 00 coast, 01 reverse, 10 forward, 11 brake. VM is the V5 bus directly. Inputs have internal 100k pull-downs; nSLEEP is pulled high (always awake). xISEN: 0.82 ohm 0603 to ground; the chip chops at VTRIP / R = 0.2-0.29 A (VTRIP 160-240 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

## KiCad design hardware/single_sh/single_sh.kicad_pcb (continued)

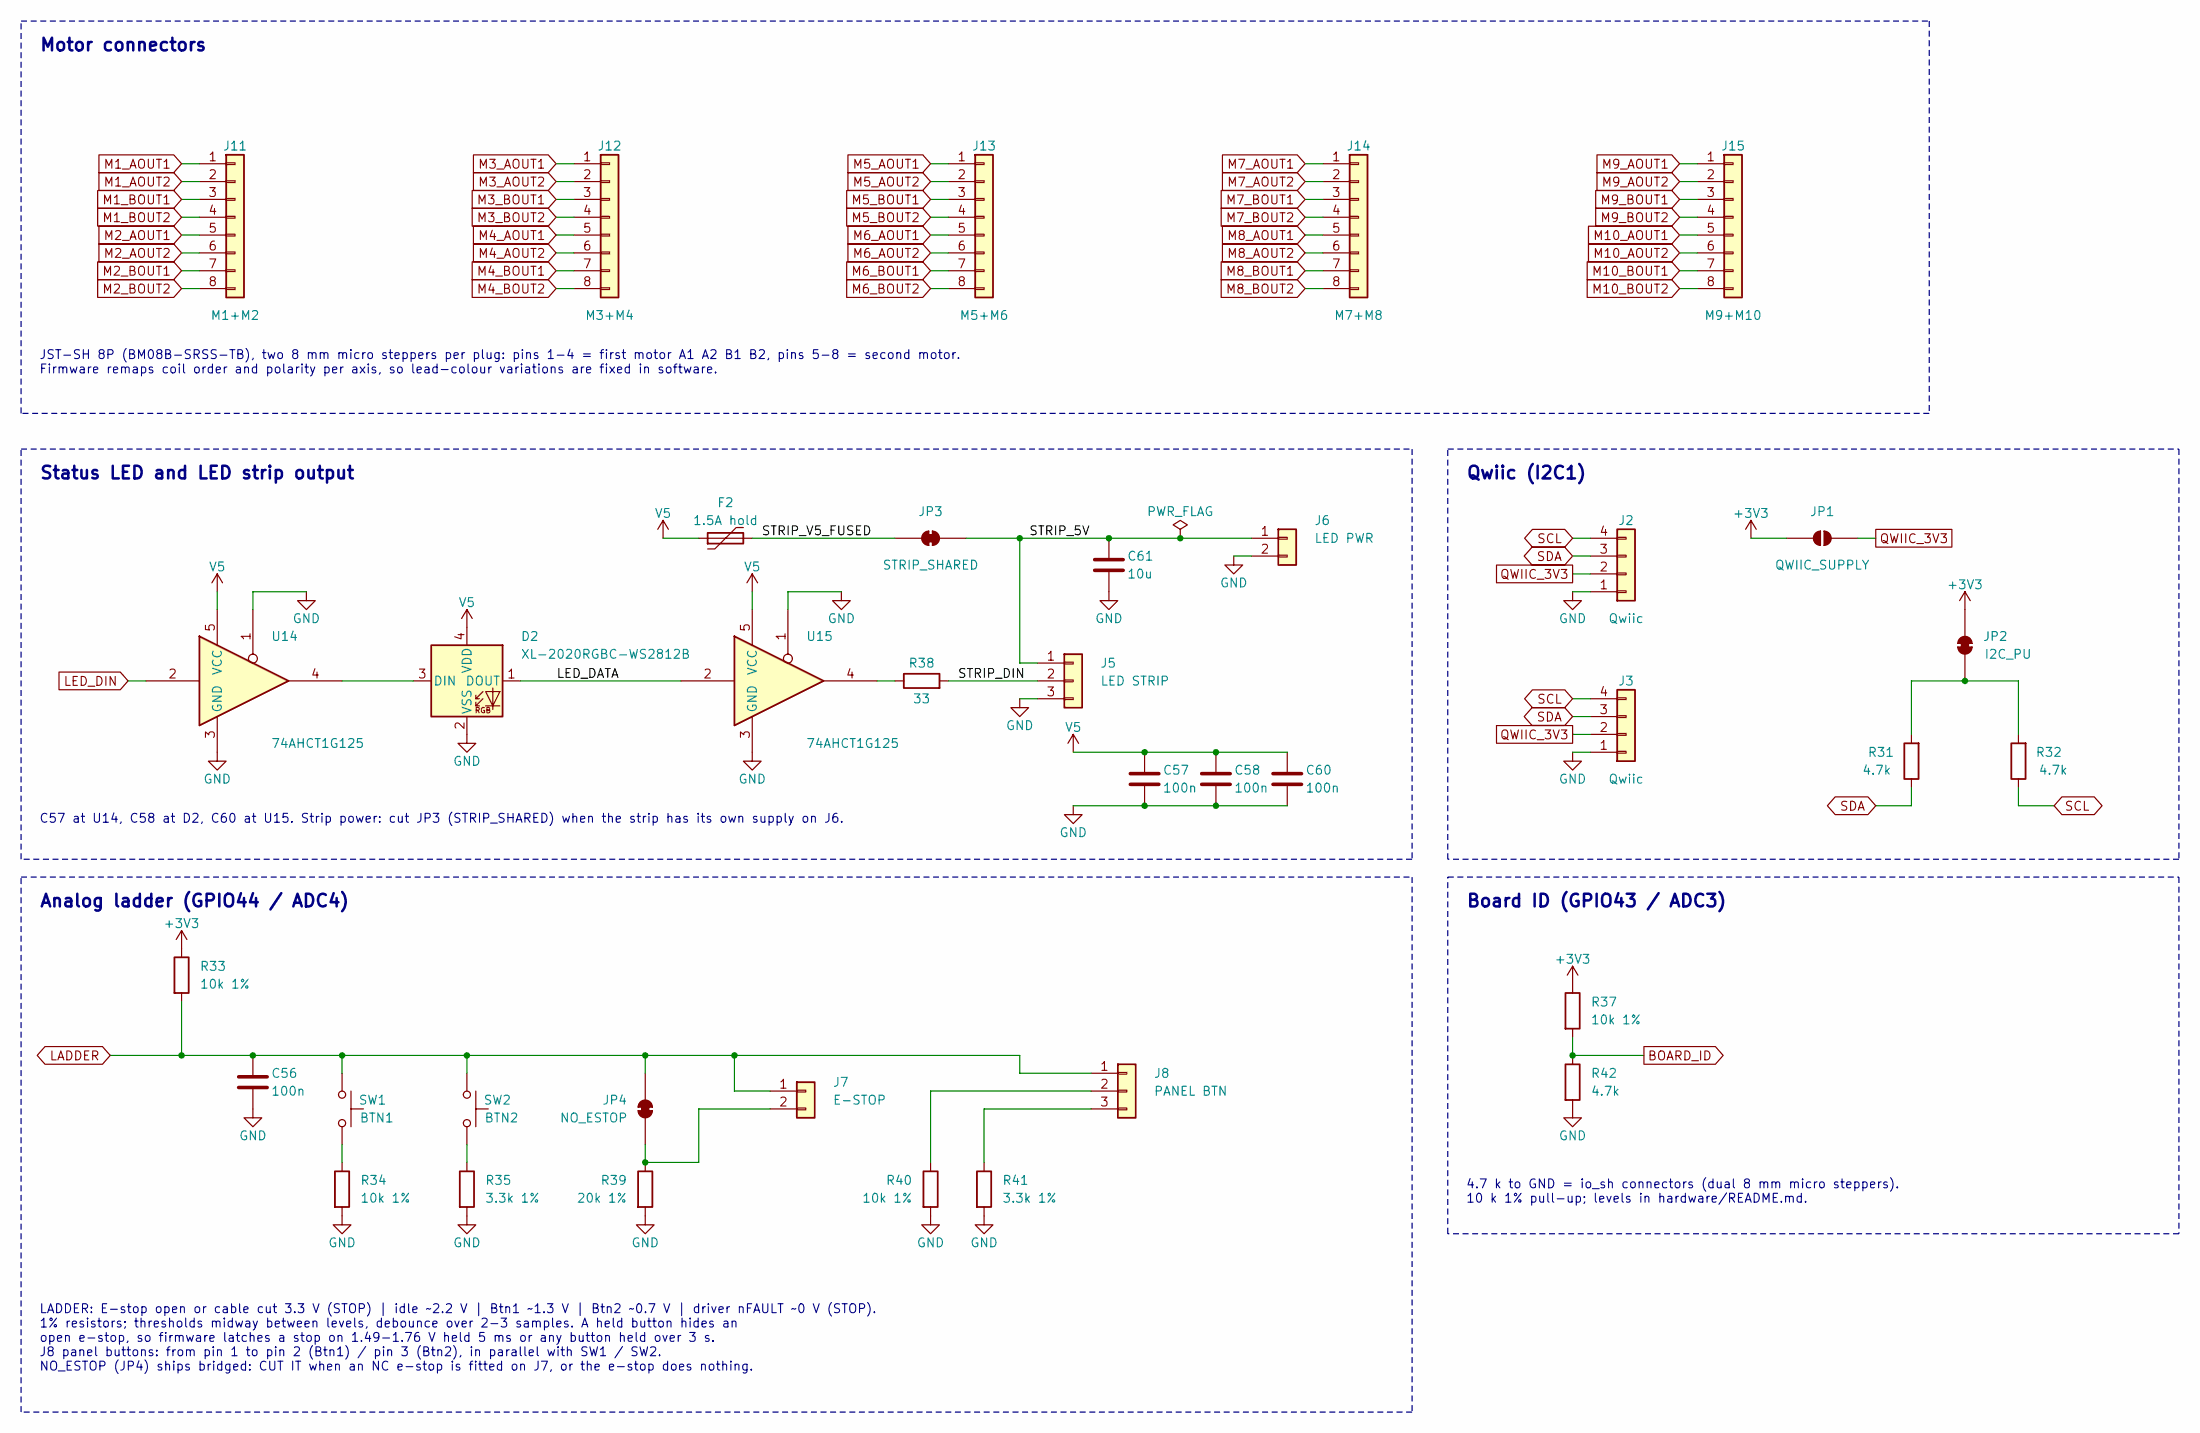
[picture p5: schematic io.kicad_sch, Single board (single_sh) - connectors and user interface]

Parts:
C56, C57, C58, C60: 100n; C_0402_1005Metric; MPN CL05B104KO5NNNC; LCSC C1525
C61: 10u; C_0805_2012Metric; MPN CL21A106KAYNNNE; LCSC C15850
D2: XL-2020RGBC-WS2812B; LED_WS2812B-2020_PLCC4_2.0x2.0mm; MPN XL-2020RGBC-WS2812B; LCSC C5349955
F2: 1.5A hold; Fuse_1812_4532Metric; MPN SMD1812P150TF/8; LCSC C209721
J2, J3: Qwiic; JST_SH_BM04B-SRSS-TB_1x04-1MP_P1.00mm_Vertical; MPN BM04B-SRSS-TB; LCSC C160390
J5: LED STRIP; JST_XH_B3B-XH-A_1x03_P2.50mm_Vertical; MPN B3B-XH-A; LCSC C144394
J6: LED PWR; JST_PH_B2B-PH-K_1x02_P2.00mm_Vertical; MPN B2B-PH-K-S; LCSC C131337
J7: E-STOP; JST_PH_B2B-PH-K_1x02_P2.00mm_Vertical; MPN B2B-PH-K-S; LCSC C131337
J8: PANEL BTN; JST_PH_B3B-PH-K_1x03_P2.00mm_Vertical; MPN B3B-PH-K-S; LCSC C131339
J11: M1+M2; JST_SH_BM08B-SRSS-TB_1x08-1MP_P1.00mm_Vertical; MPN BM08B-SRSS-TB; LCSC C160394
J12: M3+M4; JST_SH_BM08B-SRSS-TB_1x08-1MP_P1.00mm_Vertical; MPN BM08B-SRSS-TB; LCSC C160394
J13: M5+M6; JST_SH_BM08B-SRSS-TB_1x08-1MP_P1.00mm_Vertical; MPN BM08B-SRSS-TB; LCSC C160394
J14: M7+M8; JST_SH_BM08B-SRSS-TB_1x08-1MP_P1.00mm_Vertical; MPN BM08B-SRSS-TB; LCSC C160394
J15: M9+M10; JST_SH_BM08B-SRSS-TB_1x08-1MP_P1.00mm_Vertical; MPN BM08B-SRSS-TB; LCSC C160394
JP1: QWIIC_SUPPLY; SolderJumper-2_P1.3mm_Open_RoundedPad1.0x1.5mm
JP2: I2C_PU; SolderJumper-2_P1.3mm_Bridged_RoundedPad1.0x1.5mm
JP3: STRIP_SHARED; SolderJumper-2_P1.3mm_Bridged_RoundedPad1.0x1.5mm
JP4: NO_ESTOP; SolderJumper-2_P1.3mm_Bridged_RoundedPad1.0x1.5mm
R31, R32, R42: 4.7k; R_0402_1005Metric; MPN 0402WGF4701TCE; LCSC C25900
R33, R34, R37, R40: 10k 1%; R_0402_1005Metric; MPN 0402WGF1002TCE; LCSC C25744
R35, R41: 3.3k 1%; R_0402_1005Metric; MPN 0402WGF3301TCE; LCSC C25890
R38: 33; R_0402_1005Metric; MPN 0402WGF330JTCE; LCSC C25105
R39: 20k 1%; R_0402_1005Metric; MPN 0402WGF2002TCE; LCSC C25765
SW1: BTN1; SW_SPST_TS-1088-xR020; MPN TS-1088-AR02016; LCSC C720477
SW2: BTN2; SW_SPST_TS-1088-xR020; MPN TS-1088-AR02016; LCSC C720477
U14, U15: 74AHCT1G125; SOT-23-5; MPN SN74AHCT1G125DBVR; LCSC C7484

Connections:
+3V3: JP1.1 (A), JP2.2 (B), R33.1, R37.1; also elsewhere on the board
/Connectors and UI/LED_DATA: D2.1 (DOUT), U15.2
/Connectors and UI/STRIP_5V: C61.1, J5.1, J6.1, JP3.2 (B)
/Connectors and UI/STRIP_DIN: J5.2, R38.2
/Connectors and UI/STRIP_V5_FUSED: F2.2, JP3.1 (A)
BOARD_ID: R37.2, R42.1; also elsewhere on the board
GND: C56.2, C57.2, C58.2, C60.2, C61.2, D2.2 (VSS), J2.1, J3.1, J5.3, J6.2, R34.2, R35.2, R39.2, R40.2, R41.2, R42.2, U14.1, U14.3 (GND), U15.1, U15.3 (GND); also elsewhere on the board
LADDER: C56.1, J7.1, J8.1, JP4.1 (A), R33.2, SW1.1, SW2.1; also elsewhere on the board
LED_DIN: U14.2; also elsewhere on the board
M1_AOUT1: J11.1; also elsewhere on the board
M1_AOUT2: J11.2; also elsewhere on the board
M1_BOUT1: J11.3; also elsewhere on the board
M1_BOUT2: J11.4; also elsewhere on the board
M2_AOUT1: J11.5; also elsewhere on the board
M2_AOUT2: J11.6; also elsewhere on the board
M2_BOUT1: J11.7; also elsewhere on the board
M2_BOUT2: J11.8; also elsewhere on the board
M3_AOUT1: J12.1; also elsewhere on the board
M3_AOUT2: J12.2; also elsewhere on the board
M3_BOUT1: J12.3; also elsewhere on the board
M3_BOUT2: J12.4; also elsewhere on the board
M4_AOUT1: J12.5; also elsewhere on the board
M4_AOUT2: J12.6; also elsewhere on the board
M4_BOUT1: J12.7; also elsewhere on the board
M4_BOUT2: J12.8; also elsewhere on the board
M5_AOUT1: J13.1; also elsewhere on the board
M5_AOUT2: J13.2; also elsewhere on the board
M5_BOUT1: J13.3; also elsewhere on the board
M5_BOUT2: J13.4; also elsewhere on the board
M6_AOUT1: J13.5; also elsewhere on the board
M6_AOUT2: J13.6; also elsewhere on the board
M6_BOUT1: J13.7; also elsewhere on the board
M6_BOUT2: J13.8; also elsewhere on the board
M7_AOUT1: J14.1; also elsewhere on the board
M7_AOUT2: J14.2; also elsewhere on the board
M7_BOUT1: J14.3; also elsewhere on the board
M7_BOUT2: J14.4; also elsewhere on the board
M8_AOUT1: J14.5; also elsewhere on the board
M8_AOUT2: J14.6; also elsewhere on the board
M8_BOUT1: J14.7; also elsewhere on the board
M8_BOUT2: J14.8; also elsewhere on the board
M9_AOUT1: J15.1; also elsewhere on the board
M9_AOUT2: J15.2; also elsewhere on the board
M9_BOUT1: J15.3; also elsewhere on the board
M9_BOUT2: J15.4; also elsewhere on the board
M10_AOUT1: J15.5; also elsewhere on the board
M10_AOUT2: J15.6; also elsewhere on the board
M10_BOUT1: J15.7; also elsewhere on the board
M10_BOUT2: J15.8; also elsewhere on the board
unnamed: D2.3 (DIN), U14.4
unnamed: J7.2, JP4.2 (B), R39.1
unnamed: J8.2, R40.1
unnamed: J8.3, R41.1
unnamed: JP2.1 (A), R31.2, R32.2
unnamed: R34.1, SW1.2
unnamed: R35.1, SW2.2
unnamed: R38.1, U15.4
QWIIC_3V3: J2.2, J3.2, JP1.2 (B)
SCL: J2.4, J3.4, R32.1; also elsewhere on the board
SDA: J2.3, J3.3, R31.1; also elsewhere on the board
V5: C57.1, C58.1, C60.1, D2.4 (VDD), F2.1, U14.5 (VCC), U15.5 (VCC); also elsewhere on the board

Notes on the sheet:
Motor connectors
JST-SH 8P (BM08B-SRSS-TB), two 8 mm micro steppers per plug: pins 1-4 = first motor A1 A2 B1 B2, pins 5-8 = second motor. Firmware remaps coil order and polarity per axis, so lead-colour variations are fixed in software.
Status LED and LED strip output
C57 at U14, C58 at D2, C60 at U15. Strip power: cut JP3 (STRIP_SHARED) when the strip has its own supply on J6.
Qwiic (I2C1)
Analog ladder (GPIO44 / ADC4)
LADDER: E-stop open or cable cut 3.3 V (STOP) | idle ~2.2 V | Btn1 ~1.3 V | Btn2 ~0.7 V | driver nFAULT ~0 V (STOP). 1% resistors; thresholds midway between levels, debounce over 2-3 samples. A held button hides an open e-stop, so firmware latches a stop on 1.49-1.76 V held 5 ms or any button held 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
Board ID (GPIO43 / ADC3)
4.7 k to GND = io_sh connectors (dual 8 mm micro steppers). 10 k 1% pull-up; levels in hardware/README.md.

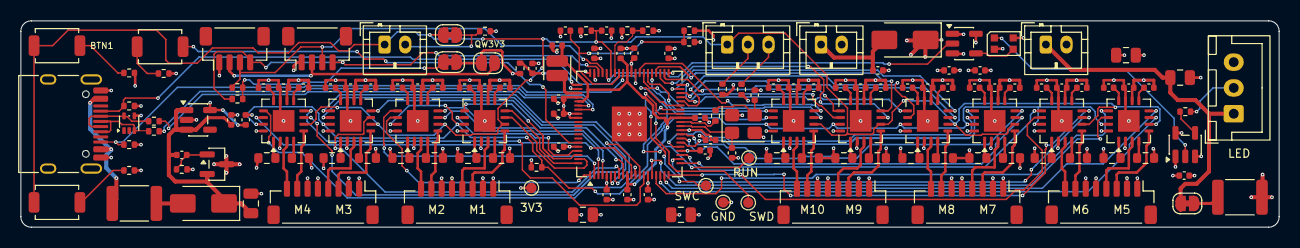
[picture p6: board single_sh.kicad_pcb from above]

Board: 4 copper layers, 122.0 x 20.0 mm, 151 parts (0 on the bottom side), 165 nets.

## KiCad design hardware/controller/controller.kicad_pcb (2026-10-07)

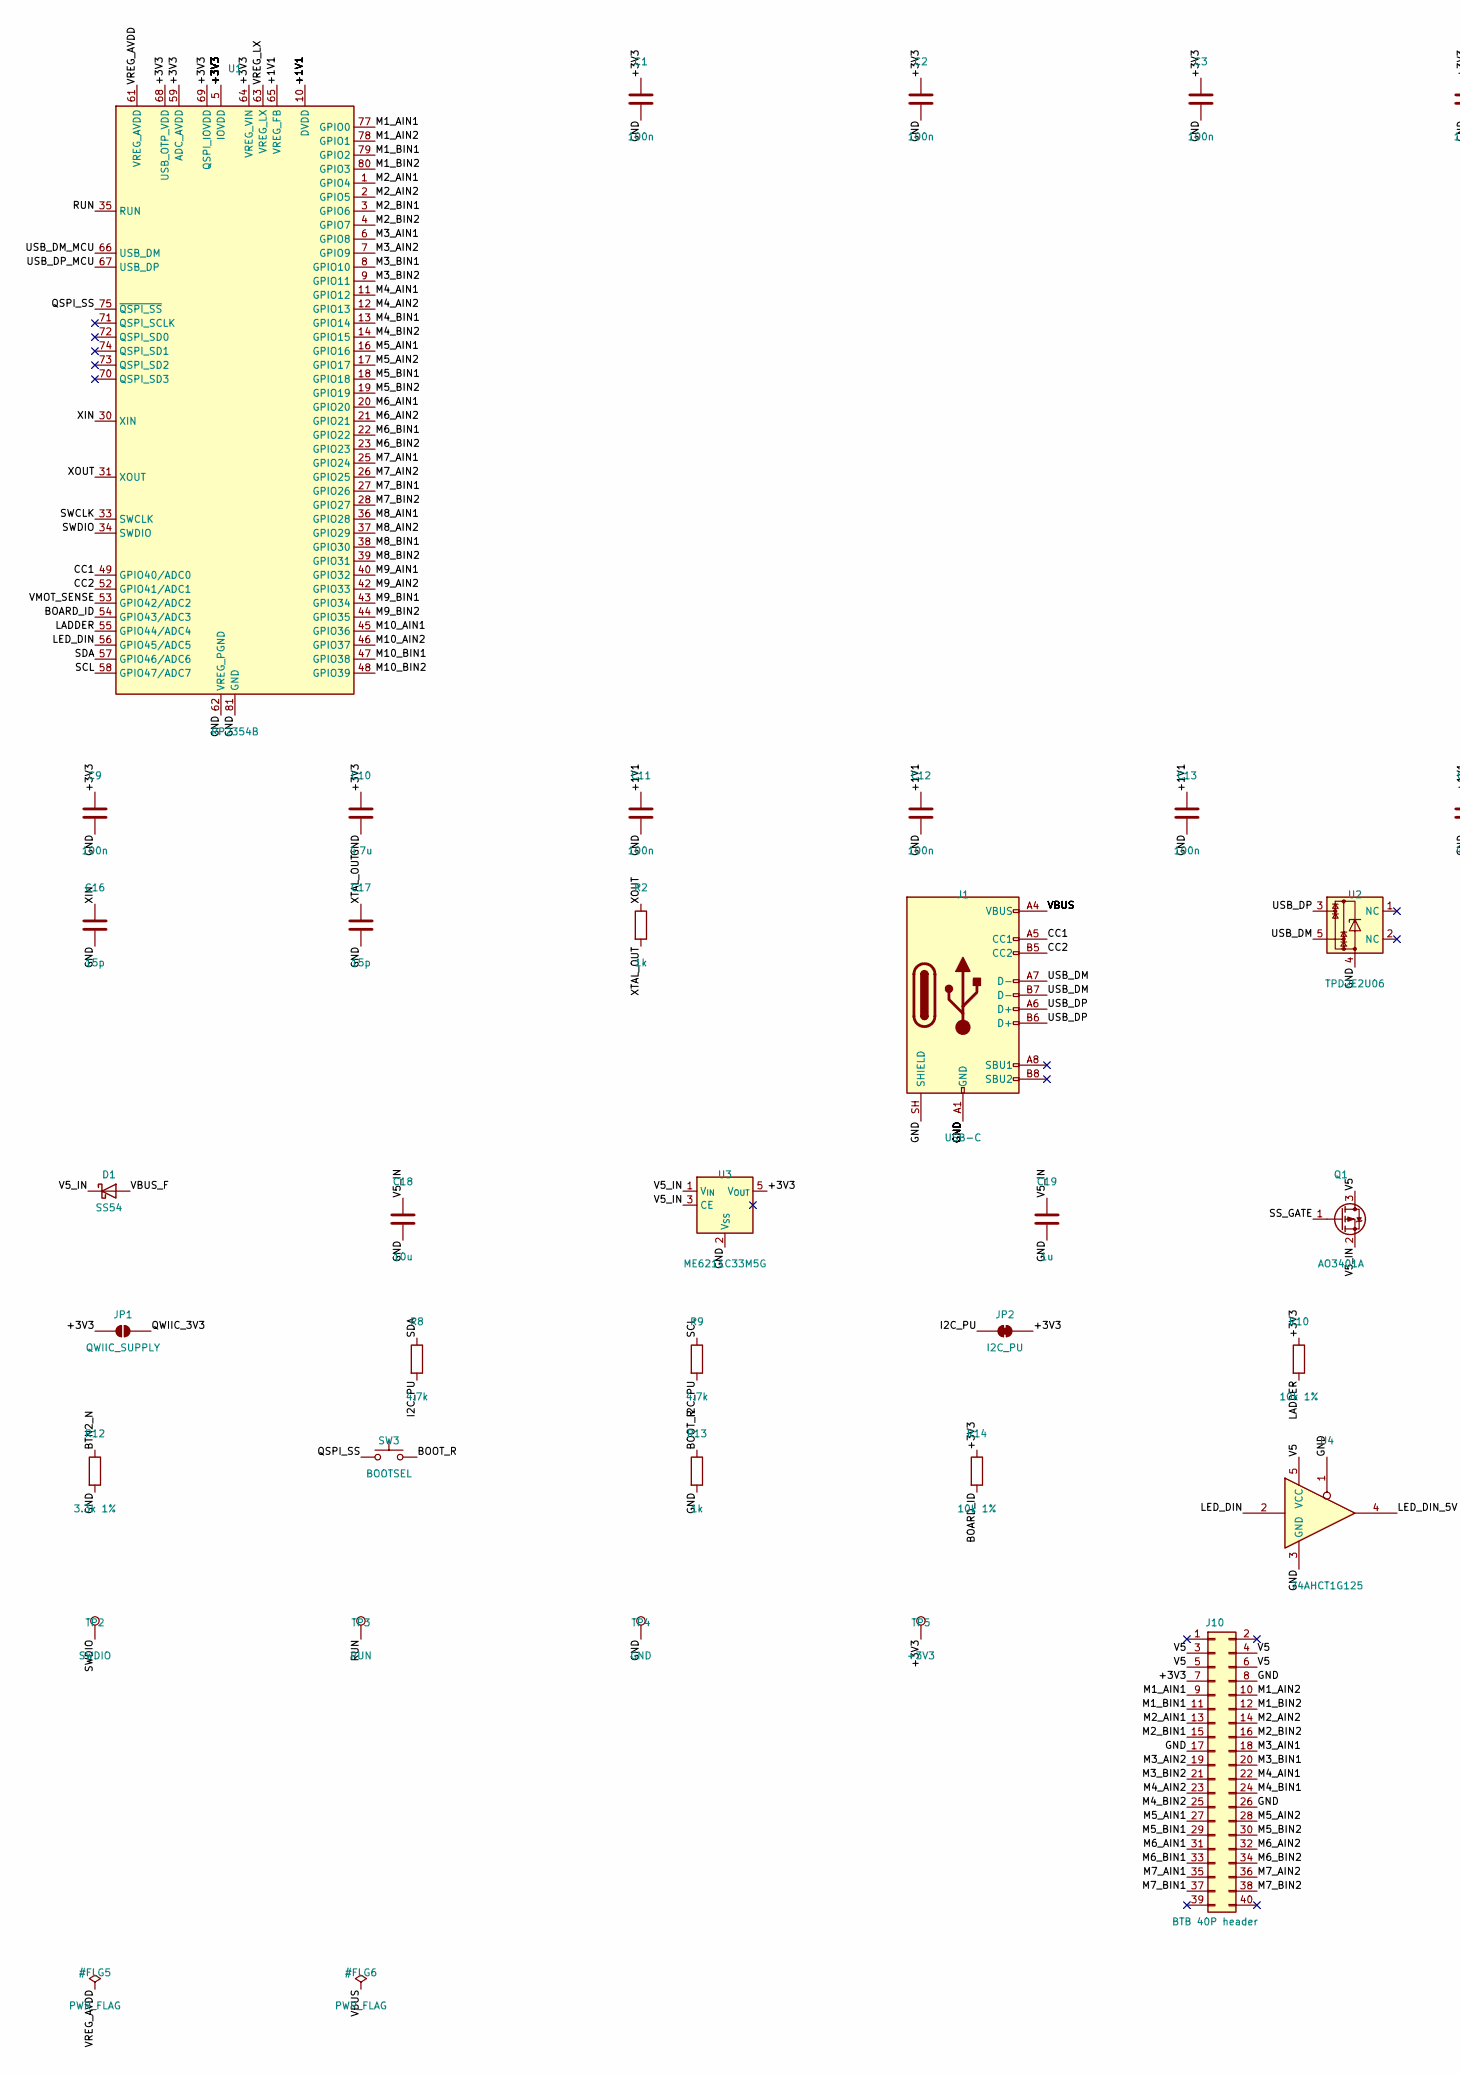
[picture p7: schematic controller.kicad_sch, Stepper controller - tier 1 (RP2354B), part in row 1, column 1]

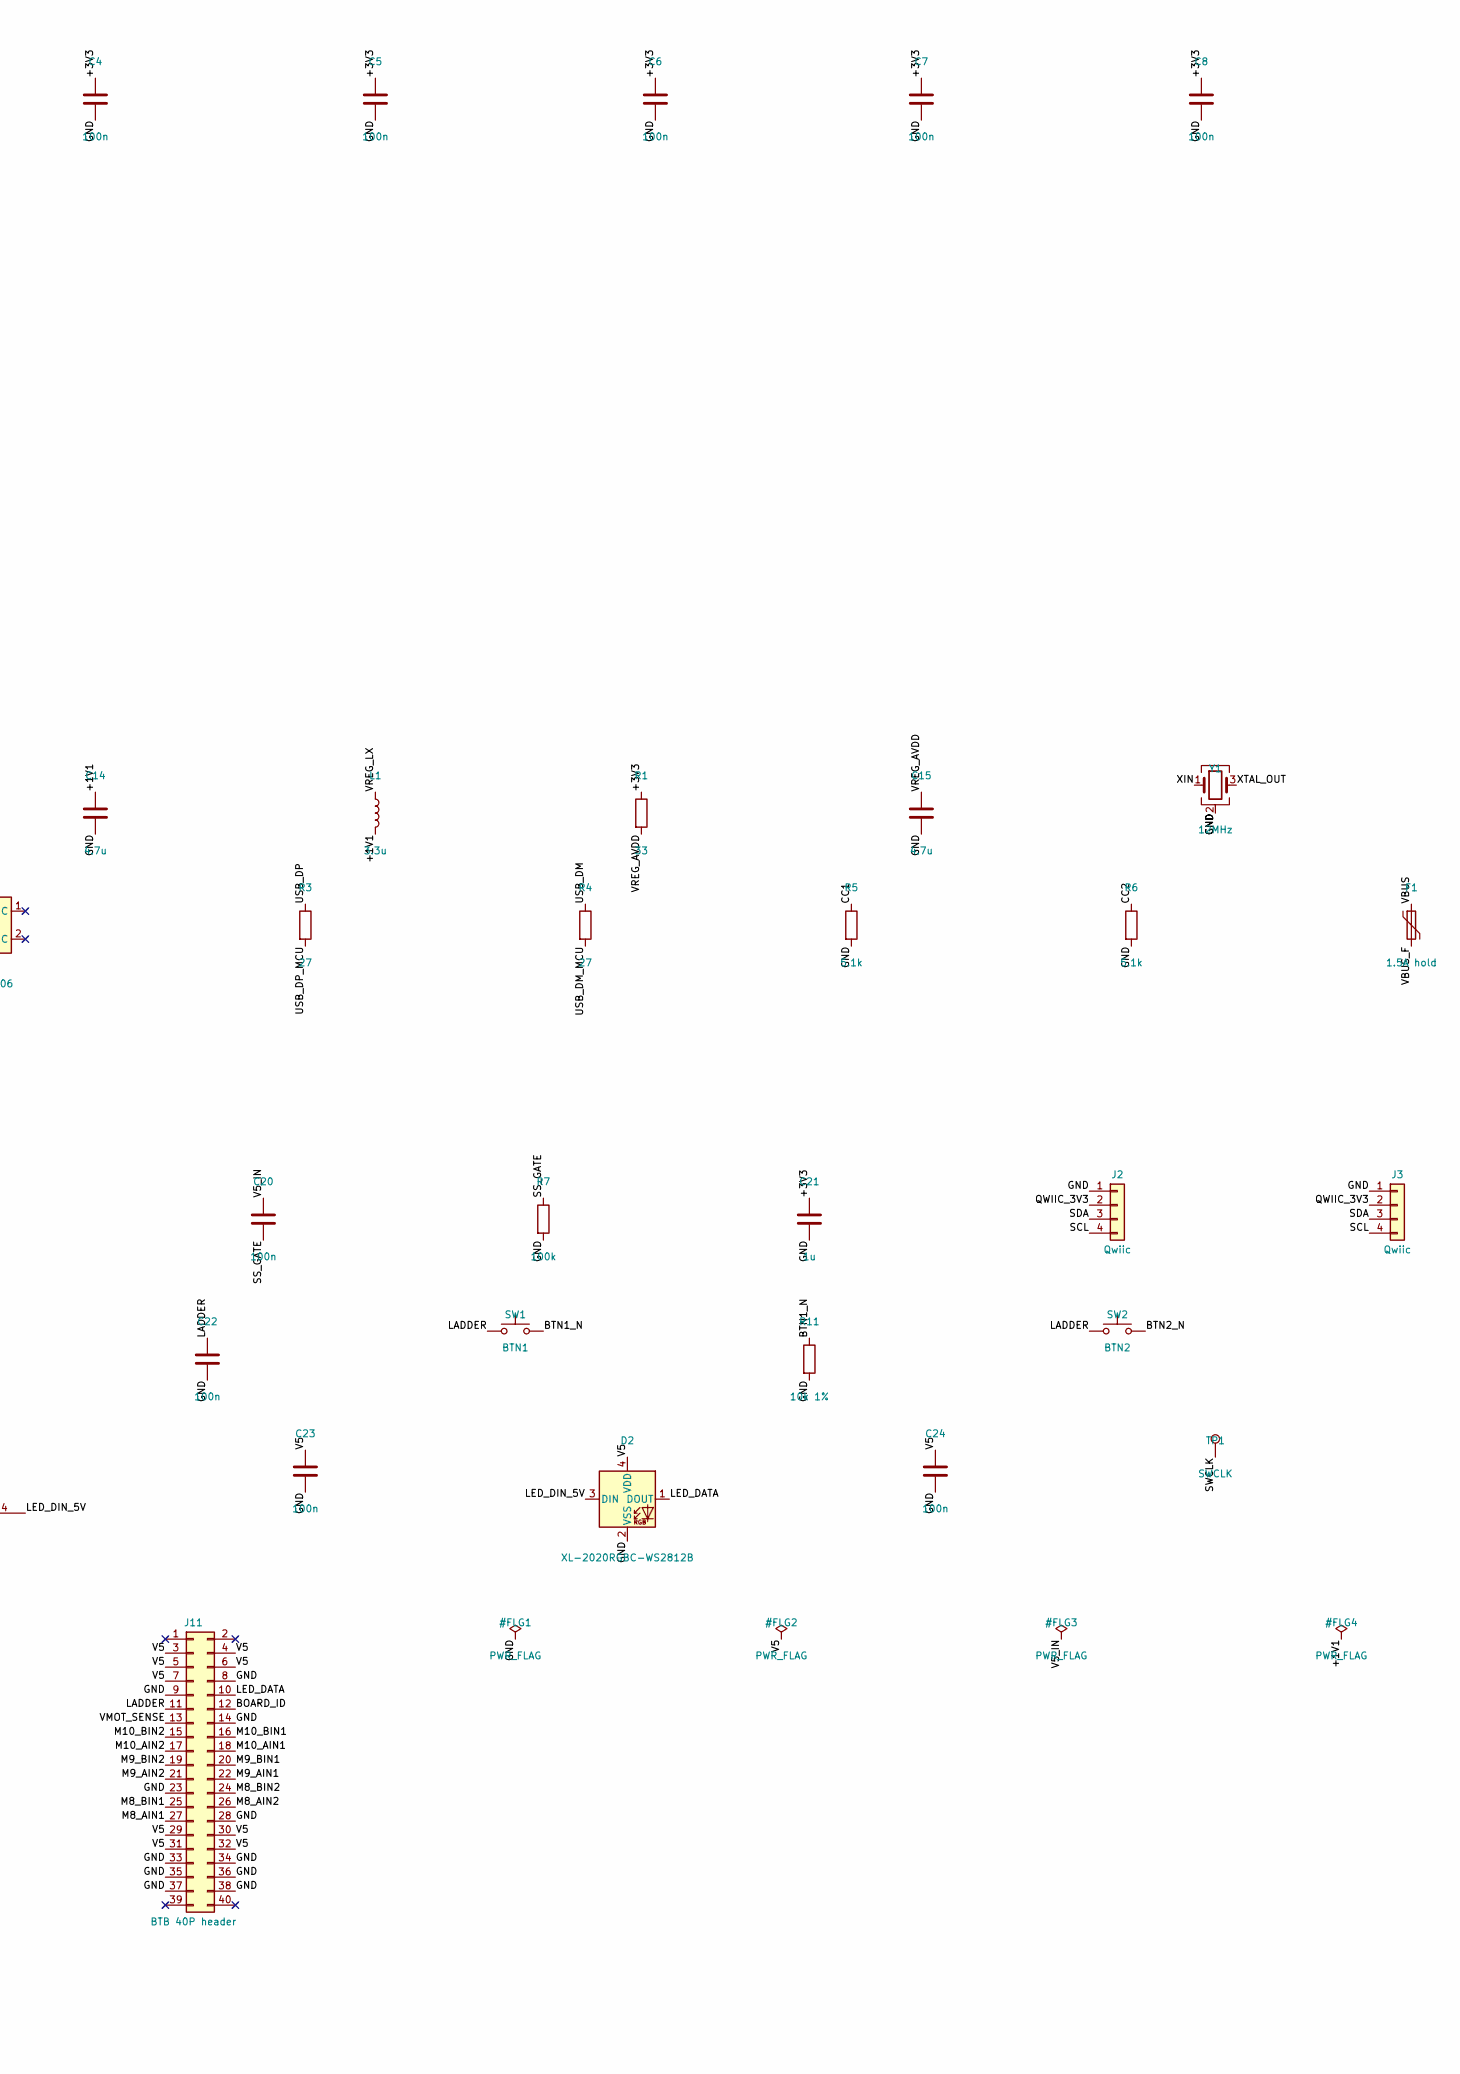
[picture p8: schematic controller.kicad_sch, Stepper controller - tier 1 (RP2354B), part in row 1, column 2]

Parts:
C1, C2, C3, C4, C5, C6, C7, C8, C9, C11, C12, C13, C20, C22, C23, C24: 100n; C_0402_1005Metric; MPN CL05B104KO5NNNC; LCSC C1525
C10, C14, C15: 4.7u; C_0402_1005Metric; MPN CL05A475MP5NRNC; LCSC C23733
C16, C17: 15p; C_0402_1005Metric; MPN 0402CG150J500NT; LCSC C1548
C18: 10u; C_0805_2012Metric; MPN CL21A106KAYNNNE; LCSC C15850
C19, C21: 1u; C_0402_1005Metric; MPN CL05A105KA5NQNC; LCSC C52923
D1: SS54; D_SMA; MPN SS54; LCSC C22452
D2: XL-2020RGBC-WS2812B; LED_WS2812B-2020_PLCC4_2.0x2.0mm; MPN XL-2020RGBC-WS2812B; LCSC C5349955
F1: 1.5A hold; Fuse_1812_4532Metric; MPN SMD1812P150TF/8; LCSC C209721
J1: USB-C; USB_C_Receptacle_HRO_TYPE-C-31-M-12; MPN TYPE-C-31-M-12; LCSC C165948
J2, J3: Qwiic; JST_SH_BM04B-SRSS-TB_1x04-1MP_P1.00mm_Vertical; MPN BM04B-SRSS-TB; LCSC C160390
J10, J11: BTB 40P header; Hirose_DF40C-40DP_Header; MPN DF40C-40DP-0.4V(51); LCSC C424643
JP1: QWIIC_SUPPLY; SolderJumper-2_P1.3mm_Open_RoundedPad1.0x1.5mm
JP2: I2C_PU; SolderJumper-2_P1.3mm_Bridged_RoundedPad1.0x1.5mm
L1: 3.3u; L_Cenker_CKCS201610; MPN AOTA-B201610S3R3-101-T; LCSC C42411119
Q1: AO3401A; SOT-23; MPN AO3401A; LCSC C15127
R1: 33; R_0402_1005Metric; MPN 0402WGF330JTCE; LCSC C25105
R2, R13: 1k; R_0402_1005Metric; MPN 0402WGF1001TCE; LCSC C11702
R3, R4: 27; R_0402_1005Metric; MPN 0402WGF270JTCE; LCSC C25100
R5, R6: 5.1k; R_0402_1005Metric; MPN 0402WGF5101TCE; LCSC C25905
R7: 100k; R_0402_1005Metric; MPN 0402WGF1003TCE; LCSC C25741
R8, R9: 4.7k; R_0402_1005Metric; MPN 0402WGF4701TCE; LCSC C25900
R10, R11, R14: 10k 1%; R_0402_1005Metric; MPN 0402WGF1002TCE; LCSC C25744
R12: 3.3k 1%; R_0402_1005Metric; MPN 0402WGF3301TCE; LCSC C25890
SW1: BTN1; SW_SPST_TS-1088-xR020; MPN TS-1088-AR02016; LCSC C720477
SW2: BTN2; SW_SPST_TS-1088-xR020; MPN TS-1088-AR02016; LCSC C720477
SW3: BOOTSEL; SW_Push_1P1T_XKB_TS-1187A; MPN TS-1187A-B-A-B; LCSC C318884
TP1: SWCLK; TestPoint_Pad_D1.0mm
TP2: SWDIO; TestPoint_Pad_D1.0mm
TP3: RUN; TestPoint_Pad_D1.0mm
TP4: GND; TestPoint_Pad_D1.0mm
TP5: +3V3; TestPoint_Pad_D1.0mm
U1: RP2354B; QFN-80-1EP_10x10mm_P0.4mm_EP3.4x3.4mm; MPN RP2354B; LCSC C39843328
U2: TPD2E2U06; SOT-553; MPN TPD2E2U06DRLR; LCSC C1972959
U3: ME6211C33M5G; SOT-23-5; MPN ME6211C33M5G-N; LCSC C82942
U4: 74AHCT1G125; SOT-23-5; MPN SN74AHCT1G125DBVR; LCSC C7484
Y1: 12MHz; Crystal_SMD_3225-4Pin_3.2x2.5mm; MPN ABM8-272-T3; LCSC C20625731

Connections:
/+1V1: C11.1, C12.1, C13.1, C14.1, L1.2, U1.10 (DVDD), U1.32 (DVDD), U1.51 (DVDD), U1.65 (VREG_FB)
/+3V3: C1.1, C2.1, C3.1, C4.1, C5.1, C6.1, C7.1, C8.1, C9.1, C10.1, C21.1, J10.7, JP1.1 (A), JP2.2 (B), R1.1, R10.1, R14.1, TP5.1, U1.5 (IOVDD), U1.15 (IOVDD), U1.24 (IOVDD), U1.29 (IOVDD), U1.41 (IOVDD), U1.50 (IOVDD), U1.59 (ADC_AVDD), U1.60 (IOVDD), U1.64 (VREG_VIN), U1.68 (USB_OTP_VDD), U1.69 (QSPI_IOVDD), U1.76 (IOVDD), U3.5 (V_{OUT})
/BOARD_ID: J11.12, R14.2, U1.54 (GPIO43/ADC3)
/BOOT_R: R13.1, SW3.2
/BTN1_N: R11.1, SW1.2
/BTN2_N: R12.1, SW2.2
/CC1: J1.A5 (CC1), R5.1, U1.49 (GPIO40/ADC0)
/CC2: J1.B5 (CC2), R6.1, U1.52 (GPIO41/ADC1)
/GND: C1.2, C2.2, C3.2, C4.2, C5.2, C6.2, C7.2, C8.2, C9.2, C10.2, C11.2, C12.2, C13.2, C14.2, C15.2, C16.2, C17.2, C18.2, C19.2, C21.2, C22.2, C23.2, C24.2, D2.2 (VSS), J1.A1 (GND), J1.A12 (GND), J1.B1 (GND), J1.B12 (GND), J1.SH (SHIELD), J2.1, J3.1, J10.8, J10.17, J10.26, J11.8, J11.9, J11.14, J11.23, J11.28, J11.33, J11.34, J11.35, J11.36, J11.37, J11.38, R5.2, R6.2, R7.2, R11.2, R12.2, R13.2, TP4.1, U1.62 (VREG_PGND), U1.81 (GND), U2.4, U3.2 (V_{SS}), U4.1, U4.3 (GND), Y1.2 (G), Y1.4 (G)
/I2C_PU: JP2.1 (A), R8.2, R9.2
/LADDER: C22.1, J11.11, R10.2, SW1.1, SW2.1, U1.55 (GPIO44/ADC4)
/LED_DATA: D2.1 (DOUT), J11.10
/LED_DIN: U1.56 (GPIO45/ADC5), U4.2
/LED_DIN_5V: D2.3 (DIN), U4.4
/M1_AIN1: J10.9, U1.77 (GPIO0)
/M1_AIN2: J10.10, U1.78 (GPIO1)
/M1_BIN1: J10.11, U1.79 (GPIO2)
/M1_BIN2: J10.12, U1.80 (GPIO3)
/M2_AIN1: J10.13, U1.1 (GPIO4)
/M2_AIN2: J10.14, U1.2 (GPIO5)
/M2_BIN1: J10.15, U1.3 (GPIO6)
/M2_BIN2: J10.16, U1.4 (GPIO7)
/M3_AIN1: J10.18, U1.6 (GPIO8)
/M3_AIN2: J10.19, U1.7 (GPIO9)
/M3_BIN1: J10.20, U1.8 (GPIO10)
/M3_BIN2: J10.21, U1.9 (GPIO11)
/M4_AIN1: J10.22, U1.11 (GPIO12)
/M4_AIN2: J10.23, U1.12 (GPIO13)
/M4_BIN1: J10.24, U1.13 (GPIO14)
/M4_BIN2: J10.25, U1.14 (GPIO15)
/M5_AIN1: J10.27, U1.16 (GPIO16)
/M5_AIN2: J10.28, U1.17 (GPIO17)
/M5_BIN1: J10.29, U1.18 (GPIO18)
/M5_BIN2: J10.30, U1.19 (GPIO19)
/M6_AIN1: J10.31, U1.20 (GPIO20)
/M6_AIN2: J10.32, U1.21 (GPIO21)
/M6_BIN1: J10.33, U1.22 (GPIO22)
/M6_BIN2: J10.34, U1.23 (GPIO23)
/M7_AIN1: J10.35, U1.25 (GPIO24)
/M7_AIN2: J10.36, U1.26 (GPIO25)
/M7_BIN1: J10.37, U1.27 (GPIO26)
/M7_BIN2: J10.38, U1.28 (GPIO27)
/M8_AIN1: J11.27, U1.36 (GPIO28)
/M8_AIN2: J11.26, U1.37 (GPIO29)
/M8_BIN1: J11.25, U1.38 (GPIO30)
/M8_BIN2: J11.24, U1.39 (GPIO31)
/M9_AIN1: J11.22, U1.40 (GPIO32)
/M9_AIN2: J11.21, U1.42 (GPIO33)
/M9_BIN1: J11.20, U1.43 (GPIO34)
/M9_BIN2: J11.19, U1.44 (GPIO35)
/M10_AIN1: J11.18, U1.45 (GPIO36)
/M10_AIN2: J11.17, U1.46 (GPIO37)
/M10_BIN1: J11.16, U1.47 (GPIO38)
/M10_BIN2: J11.15, U1.48 (GPIO39)
/QSPI_SS: SW3.1, U1.75 (~QSPI_SS)
/QWIIC_3V3: J2.2, J3.2, JP1.2 (B)
/RUN: TP3.1, U1.35 (RUN)
/SCL: J2.4, J3.4, R9.1, U1.58 (GPIO47/ADC7)
/SDA: J2.3, J3.3, R8.1, U1.57 (GPIO46/ADC6)
/SS_GATE: C20.2, Q1.1 (G), R7.1
/SWCLK: TP1.1, U1.33 (SWCLK)
/SWDIO: TP2.1, U1.34 (SWDIO)
/USB_DM: J1.A7 (D-), J1.B7 (D-), R4.1, U2.5
/USB_DM_MCU: R4.2, U1.66 (USB_DM)
/USB_DP: J1.A6 (D+), J1.B6 (D+), R3.1, U2.3
/USB_DP_MCU: R3.2, U1.67 (USB_DP)
/V5: C23.1, C24.1, D2.4 (VDD), J10.3, J10.4, J10.5, J10.6, J11.3, J11.4, J11.5, J11.6, J11.7, J11.29, J11.30, J11.31, J11.32, Q1.3 (D), U4.5 (VCC)
/V5_IN: C18.1, C19.1, C20.1, D1.1 (K), Q1.2 (S), U3.1 (V_{IN}), U3.3 (CE)
/VBUS: F1.1, J1.A4 (VBUS), J1.A9 (VBUS), J1.B4 (VBUS), J1.B9 (VBUS)
/VBUS_F: D1.2 (A), F1.2
/VMOT_SENSE: J11.13, U1.53 (GPIO42/ADC2)
/VREG_AVDD: C15.1, R1.2, U1.61 (VREG_AVDD)
/VREG_LX: L1.1, U1.63 (VREG_LX)
/XIN: C16.1, U1.30 (XIN), Y1.1
/XOUT: R2.1, U1.31 (XOUT)
/XTAL_OUT: C17.1, R2.2, Y1.3

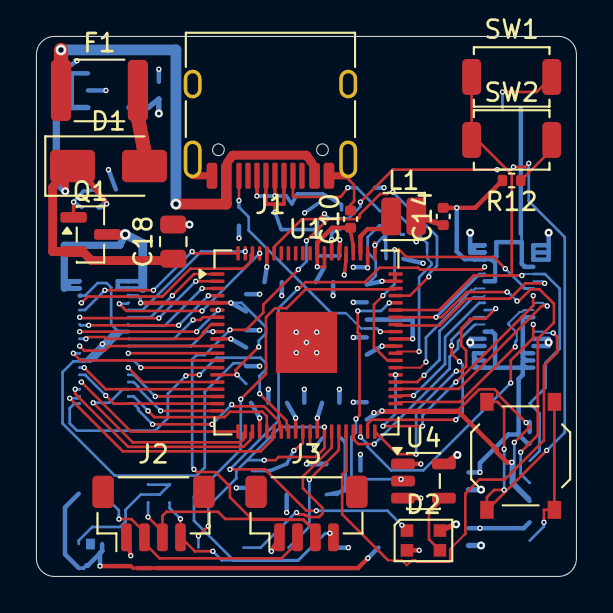
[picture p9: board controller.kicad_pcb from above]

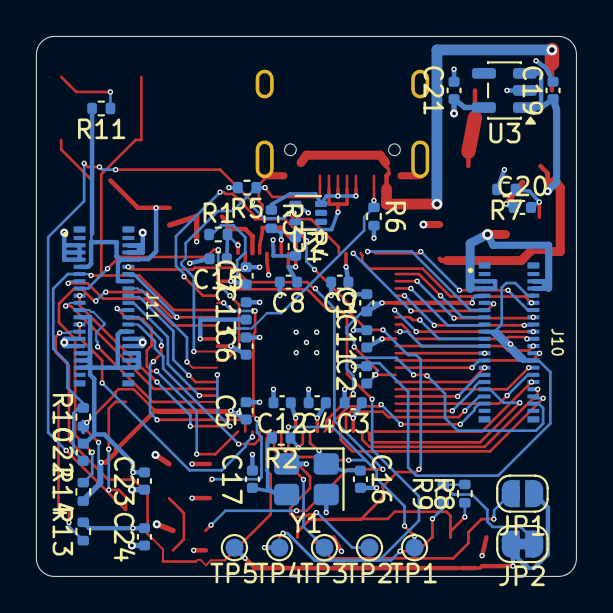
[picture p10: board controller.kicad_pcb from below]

Board: 4 copper layers, 30.0 x 30.0 mm, 63 parts (46 on the bottom side), 76 nets.

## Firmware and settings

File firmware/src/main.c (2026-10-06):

// Bench firmware for the RP2350 stepper controller.
//
// Core 1 (control.c) runs the 1 kHz trajectory tick for every axis and
// streams sine-PWM to the PIO state machines through DMA rings. Core 0 (this
// file) sets everything up, then runs the USB console (console.c), the
// status LEDs, the stress test and the core 1 watchdog.
//
// Standalone mode (standalone.h): an optional boot show starts at power-up;
// Btn1 clears a latched stop or starts / stops the selected show, Btn2
// selects (or switches to) the next stored show.
//
// LEDs: pixel 0 is the general status, pixels 1-10 show each axis (green
// forward, blue reverse, brighter = faster; dim white holding; grey stopped
// but not yet holding; red while a stop is latched).

#include <math.h>
#include <stdio.h>
#include "pico/stdlib.h"
#include "pico/multicore.h"

#include "adc_monitor.h"
#include "board_pins.h"
#include "cam_store.h"
#include "config.h"
#include "console.h"
#include "protocol.h"
#include "control.h"
#include "hbridge.h"
#include "led.h"
#include "i2c_target.h"
#include "player.h"
#include "show_store.h"
#include "standalone.h"
#include "trig.h"

#define POWER_UP_SETTLE_MS 100
// Each ring holds 3.2 ms; trip well before a stalled producer lets it wrap.
#define WATCHDOG_US 1500

// Stress test: axis i sweeps a sine of speed with its own period and phase,
// so the speed pattern rolls along the LED strip. Every STRESS_CYCLE_S all
// axes pause for STRESS_PAUSE_S to exercise stop, hold and restart.
#define STRESS_PEAK        1400.0f  // full steps/s, inside the default vmax
#define STRESS_PERIOD_S    6.0f     // axis 1; later axes slightly slower
#define STRESS_PERIOD_STEP 0.7f
#define STRESS_CYCLE_S     20.0f
#define STRESS_PAUSE_S     2.5f
#define STRESS_UPDATE_US   10000
#define LED_UPDATE_US      20000
#define LED_FULL_SPEED     1600.0f  // full brightness at this speed

hbridge_t motors[NUM_MOTORS];

static bool stress;
static uint32_t stress_start;
static bool tripped;  // core 1 watchdog fired
static config_t config;   // as loaded / last saved
static int selected_slot = -1;   // the show Btn1 starts
static int pending_slot = -1;    // start once the axes are at rest and outputs on
static bool config_from_flash;
// Core 0 idle: time spent waiting for serial input (USB interrupts that run
// during the wait count as idle, so core 0 load reads slightly low).
static uint32_t core0_idle_us;

bool app_stress_on(void) {
    return stress;
}

void app_set_stress(bool on) {
    if (on == stress)
        return;
    if (on && !control_outputs_on) {
        printf("stress test: clear the stop first (c)\n");
        return;
    }
    stress = on;
    stress_start = time_us_32();
    if (!on) {
        control_cmd_t c = {.type = CMD_STOP, .axes = CONTROL_ALL_AXES};
        control_post(&c);
    }
    printf("stress test %s\n", on ? "on" : "off");
}

const config_t *app_config(void) {
    return &config;
}

void app_set_boot_show(int slot) {
    config.boot_show = slot < 0 ? 0xff : (uint8_t)slot;
    if (slot >= 0)
        selected_slot = slot;
}

static uint32_t valid_slots(void) {
    uint32_t mask = 0;
    for (uint32_t k = 0; k < SHOW_SLOTS; k++) {
        uint32_t len;
        show_t s;
        const uint8_t *blob = show_store_blob(k, &len);
        if (blob && !show_parse(&s, blob, len, NUM_MOTORS, LED_CHAIN))
            mask |= 1u << k;
    }
    return mask;
}

static void start_show(int slot) {
    app_set_stress(false);
    const char *err = player_start((uint32_t)slot);
    if (err)
        printf("show %d not started: %s\n", slot + 1, err);
    else
        selected_slot = slot;
}

static void on_button(int button) {
    sa_state_t st = {
        .stop_latched = !control_outputs_on,
        .line_idle = control_ladder.raw_prev != LADDER_ESTOP && control_ladder.raw_prev != LADDER_FAULT,
        .running = player_slot(),
        .selected = selected_slot,
        .valid = valid_slots(),
    };
    sa_result_t r = sa_button(&st, button, SHOW_SLOTS);
    switch (r.action) {
    case SA_CLEAR:
        control_clear_request = true;
        break;
    case SA_START:
        start_show(r.slot);
        break;
    case SA_STOP:
        player_stop();
        pending_slot = -1;
        break;
    case SA_SWITCH:
        player_stop();
        pending_slot = selected_slot = r.slot;
        break;
    case SA_SELECT:
        selected_slot = r.slot;
        break;
    case SA_NONE:
        break;
    }
    printf("btn%d: %s\n", button, r.action == SA_CLEAR ? "clear stop" : r.action == SA_START ? "start show" :
           r.action == SA_STOP ? "stop show" : r.action == SA_SWITCH ? "switch show" :
           r.action == SA_SELECT ? "select show" : "nothing to do");
}

// A boot or switched-to show starts once the axes are at rest.
static void poll_pending(void) {
    if (pending_slot < 0 || player_slot() >= 0 || !control_outputs_on)
        return;
    static control_snapshot_t s;  // ~1 KB: off core 0's stack
    control_snapshot(&s);
    if (s.settled_mask != CONTROL_ALL_AXES)
        return;
    int slot = pending_slot;
    pending_slot = -1;
    start_show(slot);
}

const char *app_save_config(void) {
    static control_snapshot_t s;  // ~1 KB: off core 0's stack
    control_snapshot(&s);
    // Writing flash pauses core 1 for tens of ms while the DMA keeps
    // replaying the ring. At rest every queued period drives the same
    // electrical phase (only the amplitude may still be easing to hold),
    // so the coils just keep holding; while moving, the rotor would jerk.
    if (control_outputs_on && s.settled_mask != CONTROL_ALL_AXES)
        return "all axes must be at rest";
    config_t c = config;
    for (int i = 0; i < NUM_MOTORS; i++) {
        c.axis[i].vmax = s.vmax[i];
        c.axis[i].amax = s.amax[i];
        c.axis[i].profile = s.profile[i];
        c.axis[i].jerk_ms = s.jerk_ms[i];
        c.axis[i].drive = s.drive[i];
    }
    control_flash_busy = true;  // pauses the core 1 watchdog
    bool ok = config_save(&c);
    // Cam tables mirror what is loaded: loaded ones are stored, the rest
    // cleared (unchanged sectors aren't rewritten). The staging copies match
    // the loaded tables: core 0 only changes them through control_cam_load.
    for (uint32_t k = 0; ok && k < CAM_TABLES; k++) {
        const cam_table_t *t = &control_cam_staging[k];
        bool loaded = s.cams_loaded & (1u << k);
        ok = cam_store_write(k, t->x, t->y, loaded ? t->n : 0, t->cyclic);
    }
    control_flash_busy = false;
    if (!ok)
        return "flash write failed";
    config = c;
    config_from_flash = true;
    return NULL;
}

void app_print_status(void) {
    static uint32_t last_us;
    uint32_t now = time_us_32();
    uint32_t busy = control_busy_us, low = control_min_queued, idle0 = core0_idle_us;
    control_busy_us = 0;
    control_min_queued = HBRIDGE_RING_PERIODS;
    core0_idle_us = 0;

    if (config_from_flash)
        printf("config: saved, generation %lu\n", (unsigned long)config.generation);
    else
        printf("config: defaults (nothing saved yet)\n");
    if (player_slot() >= 0)
        printf("show %d: %s\n", player_slot() + 1, player_state());
    else if (pending_slot >= 0)
        printf("show %d: waiting for the axes to be at rest%s\n", pending_slot + 1,
               control_outputs_on ? "" : " and the stop to be cleared");
    if (config.boot_show < SHOW_SLOTS)
        printf("boot show: %d\n", config.boot_show + 1);
    printf("%s%s%s\n", tripped ? "WATCHDOG TRIPPED (X to reboot)" :
                       control_outputs_on ? "running" : "STOPPED (c to clear)",
           control_manual_amp >= 0.0f ? ", manual amplitude" : "", stress ? ", stress test" : "");

    uint32_t ladder_mv = adc_monitor_pin_mv(MON_LADDER);
    printf("  ladder %lu mV (%s%s)  vmot %lu mV  board id %lu mV",
           (unsigned long)ladder_mv, ladder_level_name(ladder_classify(ladder_mv)),
#ifdef LADDER_BYPASS
           ", BYPASSED",
#else
           control_ladder.stop_latched ? ", stop latched" : "",
#endif
           (unsigned long)adc_monitor_vmot_mv(), (unsigned long)adc_monitor_pin_mv(MON_BOARD_ID));
    if (adc_monitor_present(MON_CC1))
        printf("  cc %lu/%lu mV", (unsigned long)adc_monitor_pin_mv(MON_CC1),
               (unsigned long)adc_monitor_pin_mv(MON_CC2));

    double span = last_us ? (double)(now - last_us) : 0.0;
    printf("\n  %d motors (%d with pins), core 0 busy %.1f%%, core 1 busy %.1f%%, ring low-water ",
           NUM_MOTORS, NUM_MOTORS < BOARD_MOTORS_WITH_PINS ? NUM_MOTORS : BOARD_MOTORS_WITH_PINS,
           span > 0.0 ? 100.0 * (1.0 - idle0 / span) : 0.0, span > 0.0 ? 100.0 * busy / span : 0.0);
    if (low < HBRIDGE_RING_PERIODS)
        printf("%lu/%u periods\n", (unsigned long)low, HBRIDGE_RING_PERIODS - 1);
    else
        printf("- (no refills)\n");
    last_us = now;
}

// Pixel 0: green running, blue all holding, red blinking e-stop, magenta
// blinking driver fault, solid red watchdog trip, amber ladder bypassed.
static void update_leds(void) {
    static control_snapshot_t s;  // ~1 KB: off core 0's stack
    control_snapshot(&s);
    bool blink = (time_us_32() / 250000) & 1;
    bool on = control_outputs_on;

    if (tripped)
        led_set(LED_STATUS, 255, 0, 0);
    else if (!on)
        led_set(LED_STATUS, blink ? 255 : 0, 0,
                control_ladder.stop_cause == LADDER_FAULT && blink ? 255 : 0);
    else if (s.holding_mask == CONTROL_ALL_AXES)
        led_set(LED_STATUS, 0, 0, 255);
    else
#ifdef LADDER_BYPASS
        led_set(LED_STATUS, 255, 120, 0);
#else
        led_set(LED_STATUS, 0, 255, 0);
#endif

    for (int i = 0; i < LED_AXIS_COUNT; i++) {
        uint32_t px = LED_AXIS_FIRST + (uint32_t)i;
        if (i >= NUM_MOTORS || tripped) {
            led_set(px, 0, 0, 0);
        } else if (!on) {
            led_set(px, blink ? 120 : 0, 0, 0);
        } else if (s.holding_mask & (1u << i)) {
            led_set(px, 40, 40, 40);
        } else {
            float v = s.vel[i];
            float mag = fabsf(v) / LED_FULL_SPEED;
            uint8_t level = (uint8_t)(30.0f + 225.0f * (mag > 1.0f ? 1.0f : mag));
            if (v > 0.5f)
                led_set(px, 0, level, 0);
            else if (v < -0.5f)
                led_set(px, 0, 0, level);
            else
                led_set(px, 20, 20, 20);  // at rest, not yet holding
        }
    }
    // A running show's LED tracks take over their pixels.
    for (uint32_t px = 0; px < LED_CHAIN; px++) {
        uint8_t rgb[3];
        if (player_led(px, rgb))
            led_set(px, rgb[0], rgb[1], rgb[2]);
        else if (px >= LED_COUNT)
            led_set(px, 0, 0, 0);
    }
    led_show();
}

static void stress_update(float t) {
    float in_cycle = fmodf(t, STRESS_CYCLE_S);
    bool pause = in_cycle > STRESS_CYCLE_S - STRESS_PAUSE_S;
    for (int i = 0; i < NUM_MOTORS; i++) {
        float period = STRESS_PERIOD_S + STRESS_PERIOD_STEP * (float)i;
        float phase = 2.0f * (float)M_PI * (t / period + (float)i / (float)NUM_MOTORS);
        control_cmd_t c = {
            .type = CMD_VELOCITY,
            .axes = (uint16_t)(1u << i),
            .f1 = pause ? 0.0f : STRESS_PEAK * trig_sinf(phase),
        };
        control_post(&c);
    }
}

int main(void) {
    stdio_init_all();
#ifdef BOOT_TRACE
    sleep_ms(3000);  // give the host time to open the port
#define TRACE(...) printf(__VA_ARGS__)
#else
#define TRACE(...) ((void)0)
#endif
    TRACE("stepper bring-up, %d motor(s)\n", NUM_MOTORS);

    for (int i = 0; i < NUM_MOTORS; i++) {
        TRACE("init motor %d\n", i + 1);
        hbridge_init(&motors[i], (uint)i, i < BOARD_MOTORS_WITH_PINS);
    }
    led_init();  // after the motors: PIO2's GPIO base is set there
    adc_monitor_init();
    config_from_flash = config_load(&config);
    control_init(&config);
    // Saved cam tables; core 1 loads them on its first tick.
    for (uint32_t k = 0; k < CAM_TABLES; k++) {
        static float x[CAM_MAX_POINTS], y[CAM_MAX_POINTS];
        uint32_t n;
        bool cyclic;
        if (cam_store_read(k, x, y, &n, &cyclic))
            control_cam_load(k, x, y, n, cyclic);
    }
    sleep_us(100);  // a few ADC rounds before core 1 starts judging the ladder
    hbridge_start(motors, NUM_MOTORS);
    TRACE("PIO started\n");

    multicore_launch_core1(control_core1_main);
    TRACE("core 1 running\n");

    // Let V5 settle before driving the coils (no soft-start on V5).
    sleep_ms(POWER_UP_SETTLE_MS);
    control_energized = true;
    i2c_target_init();  // Qwiic, on boards that have it

    // Standalone: queue the boot show (it starts once outputs are on, so a
    // stop latched at power-up waits for Btn1 to clear it).
    if (config.boot_show < SHOW_SLOTS)
        pending_slot = selected_slot = config.boot_show;

    uint32_t last_beat = control_heartbeat;
    absolute_time_t beat_seen = get_absolute_time();
    bool was_on = true;
    uint32_t btn1_seen = 0, btn2_seen = 0;
    uint32_t last_stress = 0, last_led = 0;

    for (;;) {
        uint32_t now = time_us_32();
        if (now - last_led >= LED_UPDATE_US) {
            last_led = now;
            update_leds();
        }
        if (stress && now - last_stress >= STRESS_UPDATE_US) {
            last_stress = now;
            stress_update((float)(now - stress_start) * 1e-6f);
        }
        console_telemetry(now);
        player_poll(now);
        i2c_target_poll();
        if (adc_monitor_check())
            printf("ADC FIFO overflow: monitor restarted\n");

        bool on = control_outputs_on;
        if (was_on && !on) {
            stress = false;
            printf("STOP: %s, motor outputs off (c to clear)\n",
                   ladder_level_name(control_ladder.stop_cause));
        }
        if (!was_on && on)
            printf("stop cleared\n");
        was_on = on;
        if (control_clear_refused) {
            control_clear_refused = false;
            printf("cannot clear: ladder still reads %s\n",
                   ladder_level_name(control_ladder.raw_prev));
        }
        if (control_ladder.btn1_presses != btn1_seen) {
            btn1_seen = control_ladder.btn1_presses;
            on_button(1);
        }
        if (control_ladder.btn2_presses != btn2_seen) {
            btn2_seen = control_ladder.btn2_presses;
            on_button(2);
        }
        poll_pending();

        uint32_t beat = control_heartbeat;
        if (beat != last_beat || control_flash_busy) {
            last_beat = beat;
            beat_seen = get_absolute_time();
        } else if (!tripped && absolute_time_diff_us(beat_seen, get_absolute_time()) > WATCHDOG_US) {
            for (int i = 0; i < NUM_MOTORS; i++)
                hbridge_safe_off(&motors[i]);
            tripped = true;
            stress = false;
            printf("core 1 stalled: motor outputs off (X to reboot)\n");
        }

        uint32_t wait_start = time_us_32();
        int c = getchar_timeout_us(250);  // short: telemetry runs up to 1 kHz
        core0_idle_us += time_us_32() - wait_start;
        if (c != PICO_ERROR_TIMEOUT)
            protocol_input(c);
    }
}

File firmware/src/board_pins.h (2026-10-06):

#pragma once

// Application pin map. Motors always sit on GPIO 4*n..4*n+3; boards with
// fewer GPIOs run the remaining motors without pins.

#include "pico.h"

#define ADC_NONE 0xffu

#if NUM_BANK0_GPIOS > 32
// RP2354B stepper controller (hardware/README.md).
#define BOARD_MOTORS_WITH_PINS 10
#define BOARD_CC1_GPIO        40
#define BOARD_CC2_GPIO        41
#define BOARD_VMOT_GPIO       42
#define BOARD_VMOT_RATIO      5.0f   // 1:5 divider
#define BOARD_ID_GPIO         43
#define BOARD_LADDER_GPIO     44
#define BOARD_WS2812_GPIO     45
// Qwiic: I2C1 target (hardware/README.md). External pull-ups (RP2350-E9).
#define BOARD_I2C_SDA_GPIO    46
#define BOARD_I2C_SCL_GPIO    47
#define BOARD_I2C_TARGET_ADDR 0x42
#else
// Pico 2 bench (RP2350A, GPIO 0-29). Motors 1-5 on GPIO 0-19. The ladder and
// board ID go on the ADC header pins; VSYS/3 stands in for VMOTOR_SENSE.
// No free pins for the I2C target, so it is compiled out.
#define BOARD_MOTORS_WITH_PINS 5
#define BOARD_CC1_GPIO        ADC_NONE
#define BOARD_CC2_GPIO        ADC_NONE
#define BOARD_VMOT_GPIO       29
#define BOARD_VMOT_RATIO      3.0f   // Pico 2 VSYS/3 divider
#define BOARD_ID_GPIO         28
#define BOARD_LADDER_GPIO     26
#define BOARD_WS2812_GPIO     20
#endif

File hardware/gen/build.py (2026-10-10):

"""Generate the three stack schematics and the single-board versions.

    python3 build.py        # writes ../controller, ../driver, ../io_xh, ../io_sh,
                            # and the one-board versions ../single_xh, ../single_sh

single_sh is drawn as a wired, multi-sheet schematic by single_sh_sch.py; the
rest are one sheet of parts with a net label on every pin.

Passives get their LCSC / MPN from PASSIVES below; the LCSC field is only set
on parts whose number was checked (JLCPCB parts library, 2026-10-07).
"""

import os

import single_sh_sch
from schgen import Schematic

HERE = os.path.dirname(os.path.abspath(__file__))
OUT = os.path.dirname(HERE)

R0402 = "Resistor_SMD:R_0402_1005Metric"
R0603 = "Resistor_SMD:R_0603_1608Metric"
C0402 = "Capacitor_SMD:C_0402_1005Metric"
C0805 = "Capacitor_SMD:C_0805_2012Metric"
SOT23_5 = "Package_TO_SOT_SMD:SOT-23-5"
SMA = "Diode_SMD:D_SMA"
JP_BRIDGED = "Jumper:SolderJumper-2_P1.3mm_Bridged_RoundedPad1.0x1.5mm"
JP_OPEN = "Jumper:SolderJumper-2_P1.3mm_Open_RoundedPad1.0x1.5mm"
# Hirose DF40, 0.4 mm pitch, 40 pins, 2.0 mm stack: header on the underside of
# the upper board mates the socket on top of the lower board. The four corner
# contacts (pins 1, 2, 39, 40) are metal fittings per Hirose (soldered for
# strength, not for signal or power), so they are left unconnected.
BTB_HEADER = ("stack:Hirose_DF40C-40DP_Header", "DF40C-40DP-0.4V(51)", "C424643")
BTB_SOCKET = ("stack:Hirose_DF40C-2.0-40DS_Socket", "DF40C(2.0)-40DS-0.4V(51)", "C597934")
BTB_FIT = [None, None]  # one corner pair (both rows) at each end: no connect
TP = "TestPoint:TestPoint_Pad_D1.0mm"

MOTORS = 10
IN_PINS = ["AIN1", "AIN2", "BIN1", "BIN2"]
OUT_PINS = ["AOUT1", "AOUT2", "BOUT1", "BOUT2"]


def motor_nets(m, kind):
    names = IN_PINS if kind == "in" else OUT_PINS
    return [f"M{m}_{n}" for n in names]


# Pin order follows the MCU's pins so traces fan in without crossing. With the
# connectors placed pin 1 at the top: A runs down the controller's left edge
# (power by the power path, then M1 from the MCU's top-left corner, M2-M5 down
# its left side, M6-M7 round its bottom-left), B down the right edge
# (utilities high on the MCU's right side, then M10, M9, M8 round the
# bottom-right). M6/M7 sit on A so they don't cross the crystal/SWD pins.

def btb_a(kind, top):
    """40-pin connector A: motors 1-7, 3V3, 4x V5, 3x GND."""
    nets = ["V5", "V5", "V5", "V5", "+3V3" if top else "GND", "GND"]
    nets += motor_nets(1, kind) + motor_nets(2, kind) + ["GND"]
    nets += motor_nets(3, kind) + motor_nets(4, kind) + ["GND"]
    nets += motor_nets(5, kind) + motor_nets(6, kind) + motor_nets(7, kind)
    nets = BTB_FIT + nets + BTB_FIT
    assert len(nets) == 40
    return nets


def btb_b(kind, top):
    """40-pin connector B: utilities, motors 10, 9, 8, 9x V5, 11x GND."""
    nets = ["V5", "V5", "V5", "V5", "V5", "GND", "GND"]
    nets += ["LED_DATA", "LADDER", "BOARD_ID", "VMOT_SENSE" if top else "GND", "GND"]
    # The MCU's right side is numbered bottom-to-top, so each group runs reversed.
    nets += motor_nets(10, kind)[::-1] + motor_nets(9, kind)[::-1] + ["GND"] + motor_nets(8, kind)[::-1]
    nets += ["GND", "V5", "V5", "V5", "V5", "GND", "GND", "GND", "GND", "GND", "GND"]
    nets = BTB_FIT + nets + BTB_FIT
    assert len(nets) == 40
    return nets


def add_btb(sch, ref, nets, part, note):
    fp, mpn, lcsc = part
    value = "BTB 40P " + ("header" if part is BTB_HEADER else "socket")
    sch.add("Connector_Generic:Conn_02x20_Odd_Even", "J", value, fp,
            {str(i + 1): n for i, n in enumerate(nets) if n}, ref=ref, MPN=mpn, LCSC=lcsc, Note=note)


# (value, footprint) -> (LCSC, MPN). JLCPCB basic parts unless marked extended.
# Resistors are UNI-ROYAL 0402WGF thick film, 1 %, 62.5 mW.
PASSIVES = {
    ("100n", C0402): ("C1525", "CL05B104KO5NNNC"),       # 16 V X7R
    ("1u", C0402): ("C52923", "CL05A105KA5NQNC"),        # 25 V X5R
    ("2.2u", C0402): ("C170151", "CL05A225KO5NQNC"),     # 16 V X5R, extended (basic 2.2u is 6.3 V)
    ("4.7u", C0402): ("C23733", "CL05A475MP5NRNC"),      # 10 V X5R
    ("15p", C0402): ("C1548", "0402CG150J500NT"),        # 50 V C0G
    ("10u", C0805): ("C15850", "CL21A106KAYNNNE"),       # 25 V X5R
    ("0.82", R0603): ("C186570", "SR731JTTDR820F"),      # Viking 1 %, 250 mW, extended (no basic 0.82R)
    ("27", R0402): ("C25100", "0402WGF270JTCE"),         # extended
    ("33", R0402): ("C25105", "0402WGF330JTCE"),
    ("1k", R0402): ("C11702", "0402WGF1001TCE"),
    ("3.3k 1%", R0402): ("C25890", "0402WGF3301TCE"),
    ("4.7k", R0402): ("C25900", "0402WGF4701TCE"),
    ("5.1k", R0402): ("C25905", "0402WGF5101TCE"),
    ("10k", R0402): ("C25744", "0402WGF1002TCE"),
    ("10k 1%", R0402): ("C25744", "0402WGF1002TCE"),
    ("20k 1%", R0402): ("C25765", "0402WGF2002TCE"),
    ("39k 1%", R0402): ("C25783", "0402WGF3902TCE"),     # extended
    ("47k", R0402): ("C25792", "0402WGF4702TCE"),
    ("100k", R0402): ("C25741", "0402WGF1003TCE"),
}


def passive(sch, lib_id, prefix, value, fp, nets, kw):
    if "LCSC" not in kw and (value, fp) in PASSIVES:
        kw["LCSC"], kw["MPN"] = PASSIVES[(value, fp)]
    return sch.add(lib_id, prefix, value, fp, nets, **kw)


def R(sch, value, a, b, fp=R0402, **kw):
    return passive(sch, "Device:R", "R", value, fp, {"1": a, "2": b}, kw)


def C(sch, value, a, b, fp=C0402, **kw):
    return passive(sch, "Device:C", "C", value, fp, {"1": a, "2": b}, kw)


def flags(sch, *nets):
    for n in nets:
        sch.add("power:PWR_FLAG", "#FLG", "PWR_FLAG", "", {"1": n})


# ---------------------------------------------------------------------------
# Tier 1: controller
# ---------------------------------------------------------------------------
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

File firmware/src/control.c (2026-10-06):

#include "control.h"

#include <string.h>
#include "pico/stdlib.h"
#include "pico/util/queue.h"
#include "hardware/sync.h"

#include "adc_monitor.h"
#include "hbridge.h"
#include "microstep.h"
#include "pico/flash.h"

// Automatic drive amplitude per axis (config_drive_t): flat up to
// low_speed, linear up to the cap at high_speed to make up for back-EMF,
// and amp_hold once the axis has been settled for the hold delay, since
// standstill heats the coils most.
//
// Amplitude slew limit, so run/hold changes don't jerk the rotor.
#define AMP_SLEW_PER_SEC 2.0f

// One ADC round covers every monitor input; don't count the same ladder
// sample twice toward the stop debounce.
#define LADDER_EVAL_US   10

#define PERIODS_PER_TICK (HBRIDGE_PWM_HZ / MOTION_TICK_HZ)
#define CMD_QUEUE_LEN    64   // room for a 10-axis show feed plus host traffic

extern hbridge_t motors[NUM_MOTORS];  // main.c

volatile bool control_outputs_on = true;
volatile bool control_clear_request;
volatile bool control_clear_refused;
volatile bool control_energized;
volatile float control_manual_amp = -1.0f;
volatile bool control_stall_test;
volatile bool control_flash_busy;
volatile uint32_t control_heartbeat;
volatile uint32_t control_busy_us;
volatile uint32_t control_min_queued = HBRIDGE_RING_PERIODS;
ladder_t control_ladder;

static queue_t cmd_queue;

// Snapshot with a sequence lock: odd while core 1 is writing.
static volatile uint32_t snap_seq;
static control_snapshot_t snap_buf;

// Core 1 state.
static motion_axis_t axes[NUM_MOTORS];
static config_drive_t drive[NUM_MOTORS];

// Cams: tables in use on core 1, virtual leaders, and each axis's follow state.
cam_table_t control_cam_staging[CAM_TABLES];
static cam_table_t cams[CAM_TABLES];
static uint8_t cams_loaded;
static motion_axis_t vlead[VIRTUAL_LEADERS];
typedef struct {
    int8_t table;            // -1: not following
    uint8_t leader;
    int64_t offset;          // follower = f(leader) + offset
    int64_t blend;           // engage: start difference, faded out over blend_ticks
    uint32_t blend_tick, blend_ticks;
} follow_t;
static follow_t follow[NUM_MOTORS];
static uint32_t hold_delay_ms;
static group_t groups[GROUP_COUNT];
static microstep_t steppers[NUM_MOTORS];
static uint32_t rejected;
static uint32_t last_seq;
static uint32_t pvt_dropped;

void control_init(const config_t *cfg) {
    queue_init(&cmd_queue, sizeof(control_cmd_t), CMD_QUEUE_LEN);
    for (int i = 0; i < NUM_MOTORS; i++) {
        const config_axis_t *a = &cfg->axis[i];
        motion_init(&axes[i], a->vmax, a->amax);
        motion_set_profile(&axes[i], (motion_profile_t)a->profile, a->jerk_ms);
        drive[i] = a->drive;
    }
    hold_delay_ms = cfg->hold_delay_ms;
    for (int i = 0; i < NUM_MOTORS; i++) {
        follow[i].table = -1;
        snap_buf.cam_table[i] = -1;  // read by core 0 before core 1's first publish
    }
    for (int k = 0; k < VIRTUAL_LEADERS; k++) {
        motion_init(&vlead[k], 1000.0f, 2000.0f);
        motion_set_profile(&vlead[k], PROFILE_TRAP, 0);  // followers add no lag either
    }
    ladder_reset(&control_ladder, time_us_32());
}

uint32_t control_post(const control_cmd_t *cmd) {
    static uint32_t next_seq;
    control_cmd_t c = *cmd;
    c.seq = ++next_seq ? next_seq : ++next_seq;  // 0 means "failed"
    if (!queue_try_add(&cmd_queue, &c)) {
        next_seq--;
        return 0;
    }
    return c.seq;
}

const char *control_cam_load(uint32_t table, const float *x, const float *y, uint32_t n, bool cyclic) {
    static uint32_t pending_seq[CAM_TABLES];
    if (table >= CAM_TABLES)
        return "no such cam table";
    static control_snapshot_t s;  // ~1 KB: off core 0's stack
    control_snapshot(&s);
    if (pending_seq[table] && (int32_t)(s.last_seq - pending_seq[table]) < 0)
        return "previous load of this table still pending";
    for (int i = 0; i < NUM_MOTORS; i++)
        if (s.cam_table[i] == (int8_t)table)
            return "table in use (disengage its followers first)";
    const char *err = cam_build(&control_cam_staging[table], x, y, n, cyclic);
    if (err)
        return err;
    control_cmd_t c = {.type = CMD_CAM_LOAD, .ms = table};
    pending_seq[table] = control_post(&c);
    return pending_seq[table] ? NULL : "command queue full";
}

const char *control_cam_engage_check(uint32_t mask, uint32_t table, uint32_t leader) {
    static char msg[200];
    static control_snapshot_t s;  // ~1 KB: off core 0's stack
    control_snapshot(&s);
    if (table >= CAM_TABLES || !(s.cams_loaded & (1u << table)))
        return "cam table not loaded";
    if (leader >= NUM_MOTORS + VIRTUAL_LEADERS)
        return "no such leader";
    if (leader < NUM_MOTORS && s.cam_table[leader] >= 0)
        return "the leader is itself a follower";
    float lv = leader < NUM_MOTORS ? s.vmax[leader] : s.vlead[leader - NUM_MOTORS].vmax;
    float la = leader < NUM_MOTORS ? s.amax[leader] : s.vlead[leader - NUM_MOTORS].amax;
    for (uint32_t i = 0; i < NUM_MOTORS; i++) {
        if (!(mask & (1u << i)))
            continue;
        if (i == leader)
            return "an axis can't follow itself";
        if (s.cam_table[i] >= 0)
            return "already a follower";
        for (int k = 0; k < GROUP_COUNT; k++)
            if (s.group[k].active && (s.group[k].members & (1u << i)))
                return "the axis is in a group";
        for (int j = 0; j < NUM_MOTORS; j++)
            if (s.cam_table[j] >= 0 && s.cam_leader[j] == i)
                return "the axis is leading another follower";
        if (!(s.settled_mask & (1u << i)))
            return "the follower must be at rest";
        // The staging copy matches what core 1 loaded (core 0 doesn't touch it after).
        if (cam_check(&control_cam_staging[table], lv, la, s.vmax[i], s.amax[i], msg, sizeof msg))
            return msg;
    }
    return NULL;
}

void control_snapshot(control_snapshot_t *snap) {
    uint32_t s0, s1;
    do {
        s0 = snap_seq;
        __dmb();
        memcpy(snap, (const void *)&snap_buf, sizeof *snap);
        __dmb();
        s1 = snap_seq;
    } while (s0 != s1 || (s0 & 1));
}

static inline float auto_amplitude(const config_drive_t *d, float speed) {
    float v = speed < 0.0f ? -speed : speed;
    if (v <= d->low_speed)
        return d->amp_low;
    if (v >= d->high_speed || d->high_speed <= d->low_speed)
        return d->amp_high;
    return d->amp_low + (d->amp_high - d->amp_low) * (v - d->low_speed) / (d->high_speed - d->low_speed);
}

// --- cams -------------------------------------------------------------------

static const motion_axis_t *leader_of(uint8_t l) {
    return l < NUM_MOTORS ? &axes[l] : &vlead[l - NUM_MOTORS];
}

static bool is_leader(int i) {
    for (int j = 0; j < NUM_MOTORS; j++)
        if (follow[j].table >= 0 && follow[j].leader == i)
            return true;
    return false;
}
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

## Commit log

2026-10-06 Initial commit: hardware schematics and milestone 2 firmware
    Hardware: KiCad schematics and BOMs for the controller, driver and I/O
    boards (generated by hardware/gen), plus the board-to-board connector
    footprints.
    Firmware (verified on a Pico 2 + DRV8833 + 8 mm stepper):
    - 20 kHz four-segment H-bridge PWM in PIO, fed from per-motor DMA ring
    buffers in endless mode; motors 1-10 across PIO0-2.
    - Sine microstepping (1/256 step) with error diffusion for duties below
    the driver's 0.5 us minimum pulse.
    - Sine table generated offline: the SDK's float sinf returned wrong
    values near multiples of pi/2 on the RP2350, causing reverse pulses at
    each coil peak and zero crossing.
    - Constant-accel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
    [controller.kicad_sch, controller_bom.csv, driver.kicad_sch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]
2026-10-06 Add speed-dependent drive amplitude and standstill hold
    Automatic amplitude follows the bench-tuned curve for the 8 mm stepper at
    5 V: 40% up to 300 full steps/s, rising linearly to a 60% cap at 1600 to
    offset back-EMF. After 0.5 s at standstill it drops to 25% hold. Changes
    are slew-limited (2.0/s) so run/hold transitions don't jerk the rotor.
    ] / [ switch to a manual amplitude, 0 sets manual zero, a returns to auto.
    Status shows the applied amplitude and whether it is manual or holding.
2026-10-06 Milestone 3: 10 axes, ADC monitor, e-stop ladder, status LED
    - 10 motors by default. Per-board pin map (board_pins.h): RP2354B drives
    all 10; a Pico 2 drives motors 1-5 and runs 6-10 without pins so the
    full PIO/DMA/CPU load is still exercised.
    - ADC monitor: free-running round robin over ladder, VMOT, board ID and
    CC1/CC2, streamed by two chained DMA channels into fixed slots (one
    round per 10 us, no interrupts). FIFO overflow restarts it.
    - Ladder decoder (host-tested): e-stop and driver fault latch after 3
    consecutive rounds (~30 us) and core 1 drops all outputs to coast
    immediately, without waiting for the DMA rings to drain. Buttons are
    debounced 20 ms; Btn1 toggles stop/g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
    [adc_monitor.c, board_pins.h, hbridge.c]
2026-10-06 Per-axis speeds, LED axis indicators, stress test, core 0 load
    - Each axis ramps to its own target with its own amplitude curve and
    hold timer; speed commands still apply to every axis.
    - WS2812 chain: pixel 0 is the general status, pixels 1-10 show each
    axis (green forward, blue reverse, brightness by speed, dim white
    holding, red while stopped).
    - 'T' stress test: every axis sweeps a +/-1500 full steps/s sine with its
    own period and phase, pausing all axes every 20 s to exercise stop,
    hold and restart.
    - Status reports core 0 load next to core 1 and per-axis speeds.
    Measured on the Pico 2, 10 axes: core 1 ~38%, core 0 ~0.5%, ring
    low-water 62/63 periods under the stress test.
    C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
    [led.c, led.h, main.c]
2026-10-06 Add README and MIT license for public WIP release
    The README covers project goals, milestone status, repo layout, build and
    flash steps, host tests, the Pico 2 bench wiring and RP2350 gotchas found
    during bring-up. MIT covers both firmware and hardware design files.
2026-10-06 Milestone 4 slice 1: motion core, line console, telemetry
    - motion.c (host-tested): per-axis position in 2^30 units per full step
    (the low 32 bits are the electrical phase), position / velocity / jog
    modes, and a retargetable trapezoid generator. The next-speed law
    solves the discrete stopping distance exactly, so moves land on target
    with no overshoot and stay within vmax/amax; jog stops itself when not
    refreshed.
    - control.c: core 1 engine moved out of main. 1 kHz motion tick, each
    tick split exactly across its 20 PWM periods; commands arrive through
    a multicore queue, state leaves through a seqlocked snapshot.
    - console.c: line commands (m, mr, v, j, s, z, lim, amp, t, stres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
    [console.c, control.c, main.c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]
2026-10-06 Milestone 4 slice 2: motion profiles
    Five per-axis profiles, all landing exactly within vmax/amax:
    - trap: the existing retargetable trapezoid.
    - scurve (default, Tj = 30 ms): trapezoid through a moving average of
    per-tick position deltas with remainder carry, so no unit is lost;
    jerk amax/Tj per acceleration change, peaks unchanged.
    - smooth: two moving averages, continuous jerk.
    - cosine / quintic: fixed-time segments sized to the limits. Retargets
    start a quintic from the current speed and acceleration. Positions
    advance by Simpson increments and re-sync to the exact double-
    precision curve every 32 ticks; coefficients in normalized time.
    The SDK's float sinf/cosf misbehave nea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
    [console.c, control.c, main.c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]
2026-10-06 Milestone 4 slice 3: streamed PVT
    - motion.c: per-axis queue of 32 position/velocity/time points; each
    segment is a cubic Hermite from the current state, landing exactly on
    every point. 'pgo' starts the listed axes on the same tick, only from
    rest. Running dry while moving brakes at amax and counts an underrun;
    a final v = 0 point stops exactly there. PVT bypasses the profile
    filters (the host shapes the motion); any other command abandons the
    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
2026-10-06 Milestone 4 slice 4: configurable telemetry and events
    - t <hz> up to 1000; ta selects axes; tf per-axis fields (pos, vel,
    mode, amp, q); ts system fields (seq, vmot, ladder, stop). A '#'
    header names the columns whenever the layout changes; every line
    carries a counter so hosts can detect drops.
    - Commands carry sequence numbers; 'seq' reports the last one core 1
    applied, so a host can tell when its commands took effect.
    - te on: event lines for finished moves, PVT underruns, stop latched
    and cleared.
    - Lines are built with integer formatting and written in one call:
    float printf was too slow for 10 axes at 1 kHz.
    - Core 0 polls input every 250 us to keep up.
    On the Pico 2: 100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
    [console.c, control.c, main.c]
2026-10-06 Milestone 5 slice 1: coordinated groups and planner
    group.c (host-tested): a group owns a set of axes (at rest to join; one
    owner per axis) and follows a queue of straight segments in joint space.
    - Path speed / acceleration per segment are limited so no member axis
    exceeds its own vmax / amax.
    - Junction speed: no axis's speed may jump by more than amax * corner
    time (default 20 ms). A backward pass over the queue keeps every entry
    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
2026-10-06 Fix group stop leaving the group held when the queue ends first
    If a stop's deceleration ran past the end of the queue, the group went
    idle with hold and flush_on_stop still set, so it refused new moves.
    Completing the queue now finishes the stop. Host test reproduces the
    case (fails on the previous code).
    Found under load on the Pico 2: 4 groups on all 10 axes running dense
    arcs (~550 chords/s each) measured core 1 at 38.7% (45.5% with 1 kHz
    full telemetry, core 0 at 31.9%), ring low-water never below 56/63.
    [test_host.c]
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2026-10-06 Milestone 6 slice 1: configuration in flash
    config.c: per-axis vmax/amax, profile and jerk time, and a new per-axis
    drive section (automatic amplitude curve: run low/high, hold, corner
    speeds; flags: reverse direction, swap coils), plus the hold delay.
    Records live in the last two flash sectors, written alternately with a
    generation counter and CRC-32; loading picks the newest valid one, so a
    torn save keeps the previous configuration. Record format, CRC and
    selection (incl. generation wrap and erased sectors) are host-tested.
    Saving pauses core 1 through flash_safe_execute, so it is only allowed
    with every axis at rest and holding: the DMA then replays identical hold
    periods, and the core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
    [__main__.py, console.c, control.c]
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2026-10-06 Electronic cams with virtual leaders
    cam.c (host-tested): cam tables map leader position to follower
    position with cubic Hermite / Catmull-Rom slopes (C1). Cyclic tables
    repeat with an optional net rise per cycle, counted in exact integer
    arithmetic (exact over +-1e6 cycles); one-shot tables hold their ends.
    Being position-based, followers retrace exactly when the leader
    reverses, at any speed.
    Core 1: MODE_CAM followers read their leader's freshly updated position
    each tick (virtual leaders, then axes and groups, then followers). Two
    virtual leaders are motor-less axes with their own ramps. Engaging
    blends the start difference out with a smoothstep; stop disengages with
    a ramp down. Follow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
    [__main__.py, console.c, control.c]
2026-10-06 Save cam tables in flash; fix a core 0 stack overflow
    Cam tables: one flash sector per table below the show slots, each record
    with magic, version and CRC (cam_store.c; format host-tested). `save`
    (console, binary, host tool) mirrors what is loaded: loaded tables are
    written, unloaded ones cleared, unchanged sectors left alone. Saved
    tables are loaded at boot. control_init now marks every axis "not a
    follower" in the snapshot before core 1's first publish; otherwise the
    boot-time load saw table 1 as in use and refused it.
    Stack overflow (found while testing this): a save over the binary
    protocol hung the controller hard (no USB, no picotool reset). The call
    chain protocol_input -> dispatch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
    [console.c, control.c, main.c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]
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2026-10-06 Schematic review fixes from datasheet checks
    - Crystal: Abracon ABM8-272-T3, which the RP2350 design guide's
    15 pF / 1k values are tuned for (the YXC part needs 20 pF load).
    - Status LED: power from V5 and buffer the 3.3 V data through a
    74AHCT1G125; the diode drop left VDD below the 3.7 V minimum.
    - Qwiic: drop the BAT54WS power-in path. The ME6211 conducts from
    VOUT to VIN, so a Qwiic-fed 3V3 would back-power V5.
    - Notes: sense resistors chop at 0.2-0.29 A rather than fault;
    the NO_ESTOP jumper must be cut when an e-stop is fitted.
    - README: AT8833 capacitor values, inductor orientation, VMOT_SENSE
    limits, and open items (V5 capacitance, e-stop masking by a held
    button, E9 rese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
    [controller.kicad_sch, controller_bom.csv, driver.kicad_sch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]
2026-10-06 Add RC soft-start P-FET on the V5 bus
    The ~70 uF across the stack charged straight from USB at plug-in.
    An AO3401A between V5_IN and V5, with 100 nF gate-source and 100k
    gate-ground (tau 10 ms), turns on over a few ms so the bus charges
    at about 0.1 A. The LDO moves to V5_IN ahead of the switch; external
    5 V on tier 3 reaches V5_IN through the body diode, then the channel.
    Inrush is estimated, to be measured on the first boards.
    [controller.kicad_sch, controller_bom.csv]
2026-10-06 Ladder: stop when a held button hides an open e-stop
    E-stop open + Btn1 reads 1.65 V and + Btn2 reads 0.82 V, both inside
    the button bands, so an e-stop opened while a button was held went
    unnoticed until release.
    - 1.49-1.76 V held 5 ms latches an e-stop (a Btn1 release crosses
    that band for ~0.2 ms).
    - Any button held over 3 s latches an e-stop, covering the Btn2 case
    (too close to Btn2 alone to split) and a stuck button.
    - Such a level is not counted as a press, and the stop can't be
    cleared until the line returns to idle.
    Host tests cover both cases and fail against the old decoder.
    [test_host.c]
2026-10-06 Motor pins: disable input buffers; close the E9 reset item
    RP2350-E9 (a GPIO with input enabled can sit near 2.2 V, above the
    AT8833's 2 V VIH) is fixed from stepping A3, and A4 is production,
    so the board needs no stronger pull-downs. On A2 (bench Pico 2) it
    can't occur after power-on or RUN reset; the motor pins are never
    read, so their input buffers are now turned off at PWM init and in
    safe-off, which also covers a watchdog reset.
    [hbridge.c]
2026-10-06 Board-ID table with 5% resistors; crystal LCSC number
    Eight levels from common 0402 values (0, 1k, 2.2k, 4.7k, 10k, 22k,
    47k, not fitted) against the controller's 10k 1% pull-up. Worst case
    with 5% ID resistors, adjacent levels stay >= 249 mV apart. io_xh
    keeps 10k and io_sh 4.7k, now 5%; other rows are left free.
    ABM8-272-T3 is LCSC C20625731.
    [controller.kicad_sch, controller_bom.csv, io_sh.kicad_sch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]
2026-10-06 Stack: DF40 2.0 mm connectors, 30x30 boards, controller placement
    - BTB: Hirose DF40 40-pin, 2.0 mm stack (header DF40C-40DP C424643,
    socket DF40C(2.0)-40DS C597934). The 0.8 mm XUNPU stack left no room
    for parts between boards (the driver QFNs alone are 0.75-0.8 mm).
    Corner contacts are metal fittings per Hirose: tied to GND, not used
    for current. Footprints generated from the catalogue layouts; the
    header's rows are mirrored so pin n mates pin n after the flip.
    - Repin: A carries M1-M7, B carries M8-M10 and the utilities, in the
    MCU's pin order so the controller's traces fan in without crossing.
    13 V5 pins across both connectors (was 6).
    - Boards grow to 30 x 30 mm; controlle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
    [controller.kicad_pcb, controller.kicad_sch, controller_bom.csv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]
2026-10-06 Controller: route MCU supplies, crystal and core regulator
    - Exposed-pad GND vias; every 3V3/1V1 pin vias to its underside 100 nF
    (3V3 vias land on the In2 plane), each cap with its own GND via.
    - Crystal on the underside next to XIN/XOUT, with load caps and the
    1k XOUT resistor.
    - Core regulator: short LX to L1 on top, PGND via, VIN cap over pin 64,
    1V1 cap by L1, AVDD RC moved to the underside behind L1.
    - 1V1: In2 track from L1 to all four DVDD pins, ringed round the EP.
    - USB-C 2 mm left of centre to make room for L1.
    - Power net class clearance 0.15 -> 0.1 mm (JLCPCB standard), so the
    under-chip vias fit.
    The PCB is the source from here; gen/pcbgen.py no longer recreates it.
    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
    [controller.kicad_pcb]
2026-10-06 Controller: route USB and the power path; TPD2E2U06 ESD
    - ESD: USBLC6-2SC6 -> TPD2E2U06DRLR (SOT-553, C1972959) so it fits on
    the D+/D- path. Footprints re-linked to the regenerated symbols.
    - USB: D- pads joined on top, D+ via-joined below; underside pair
    through the ESD and 27R series resistors back up to pins 66/67. CC1
    and CC2 5.1k to GND; VBUS lane above the pad row, then underside to F1.
    - Power: F1 -> SS54 -> V5_IN -> AO3401A soft-start -> V5; LDO on V5_IN
    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
    [controller.kicad_pcb, controller.kicad_sch, controller_bom.csv]
2026-10-06 Controller: autoroute most signals with Freerouting (checkpoint)
    GND/3V3 pad vias added; Freerouting 2.5.0 routed most of the BTB
    fan-out and small signals (hand routing kept locked). 31 nets remain
    unconnected around the BTB / button / MCU fan-out. Default vias
    0.3/0.15 mm; Power tracks 0.25 mm.
    [controller.kicad_pcb]
2026-10-06 Controller: fully routed
    - BTN1/BTN2 -> XUNPU TS-1088-AR02016 (C720477), stacked in the top-right
    corner with R11/R12 under them: the TS-1187A pads over the BTB headers
    blocked the connector fan-out.
    - Connector B moved 2 mm down (stack still keyed by A's +2 mm offset);
    ladder/board-ID resistor column moved right, out of the M8 path.
    - BTB corner contacts left unconnected (Hirose metal fittings).
    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
    [controller.kicad_pcb, controller.kicad_sch, controller_bom.csv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]
2026-10-07 single_sh: routed single-board PCB; BOM scrub
    New single-board versions of the circuit (controller + driver + IO variant
    on one PCB, BTBs removed): single_sh and single_xh schematics from single()
    in gen/build.py. single_sh also gets a routed board:
    - 122 x 20 mm, 4 layers, 1.6 mm, all parts on top. In1 GND; In2 V5 with a
    3V3 island under the MCU (thin finger to the LDO); F/B signals.
    - Along the board: USB-C + power | drivers M4-M1 | MCU | drivers M10-M5 |
    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
    [controller.kicad_pcb, controller.kicad_sch, controller_bom.csv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]
2026-10-08 single_sh: 0805 sense resistors; JLCPCB fab output
    Sense resistors move from 0402 (62.5 mW) to 0805 (125 mW, Yageo
    RL0805FR-070R82L, C513694); holding a coil at the current-limit trip is
    now 56 % of rating. Driver-cell bottoms re-routed for the larger pads
    (BOUT2 between the ISEN pads, BOUT1 under R_B), seven input nets
    re-routed, motor labels moved onto the connectors. DRC: 0 unconnected,
    no copper violations.
    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
    [driver.kicad_sch, driver_bom.csv, single_sh.kicad_pcb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]
2026-10-09 single_sh: wired multi-sheet schematic
    Replace the label-on-every-pin single_sh schematic with a presentable
    hierarchical drawing: overview, power and USB, MCU, motor drivers,
    connectors and UI (A3 sheets). Parts are wired, rails use power symbols,
    inter-sheet signals use global labels, each block is framed with design
    notes from the README.
    - gen/schdraw.py draws wires/labels/power symbols and traces the drawing
    the way KiCad does; the build fails unless every pin is on the net
    build.py gave it. gen/single_sh_sch.py holds the layout.
    - AT8833CQ gets a project symbol (lib/stack.kicad_sym, DRV8833RTY pin
    numbers) arranged so each driver cell draws without crossings.
    - Same circuit: KiC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
    [drivers.kicad_sch, io.kicad_sch, mcu.kicad_sch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]
2026-10-10 PCB route cleanup
    A few human reroutes
    [single_sh.kicad_pcb]
2026-10-10 single_sh: 0603 sense resistors; refilled zones, fab output
    Sense resistors move from 0805 to 0603 (Viking SR731JTTDR820F, C186570,
    250 mW); holding a coil at the current-limit trip is now 28 % of rating.
    Swapped in place on the routed board: ISEN pad kept, GND pad 0.275 mm
    inboard (R5/R11 keep the GND pad instead). Zones refilled after the route
    cleanup and trace edits. DRC: 0 unconnected, 0 parity, no copper
    violations; 4 silkscreen warnings.
    Schematics, BOMs, generators and README updated; JLCPCB Gerbers/BOM/CPL
    regenerated and placement-checked.
    [driver.kicad_sch, driver_bom.csv, drivers.kicad_sch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]
2026-10-11 single_sh_proto: all-0603 basic-parts prototype board, as ordered
    150 x 30 mm 4-layer board, fully routed (0.52/0.3 vias, 45-degree traces,
    centred pad entries, no vias in pads), JLCDFM clean. Corrected nested
    dual-motor connector pinout, bring-up test points, back-silk squid art.
    L1 substituted (C411344); status LED D2 is the 5050 WS2812B (C2843785),
    left off the Economic PCBA order for hand soldering.
    Generator updates for the proto board (build.py, pcbgen.py, jlcfab.py,
    single_sh_sch.py, add_testpoints.py, squid_silk.py) and regenerated
    outputs for the other boards.
    Ordered from JLCPCB 2026-10-11: 5 boards, Economic PCBA.
2026-10-12 firmware: single_sh_proto board target
    PICO_BOARD=single_sh_proto: same GPIO map as rp2354b_stepper (checked
    against the proto netlist), VMOT ratio 4.9 for the 39k/10k divider, and
    odd motors default to SWAP_COILS|REVERSE for the nested connector pinout.
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
